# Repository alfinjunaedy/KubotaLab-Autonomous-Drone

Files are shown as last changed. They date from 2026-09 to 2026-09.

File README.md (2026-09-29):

# Autonomous Drone

<p align="center">
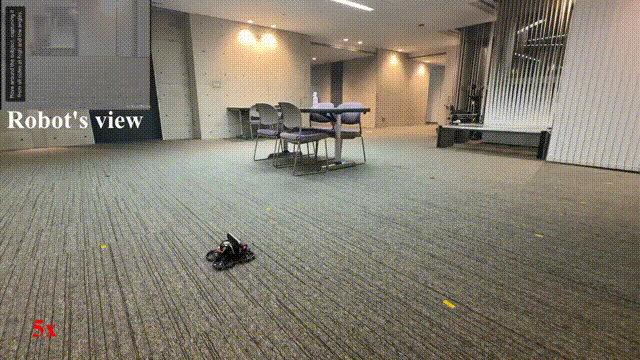
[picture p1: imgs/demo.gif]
Autonomous flight demo
  
</p>

Compact autonomous quadcopter built around a Raspberry Pi Zero 2 W. It estimates its position from an IMU, optical flow, and an altitude ToF sensor, then closes the loop on position and velocity onboard — no external positioning system required.

## Hardware

| | |
|---|---|
| Dimensions | 205 (L) × 205 (W) × 110 (H) mm |
| Weight | 877 g |
| Battery | Li-ion 6S pack (~5 min flight time) |
| Onboard controller | Raspberry Pi Zero 2 W |
| Sensors | IMU · optical flow · altitude ToF · A/D converter |
| Payload | iPhone 16 Pro |
| Flight controller | 4-in-1 ESC (Betaflight) |

<p align="center">
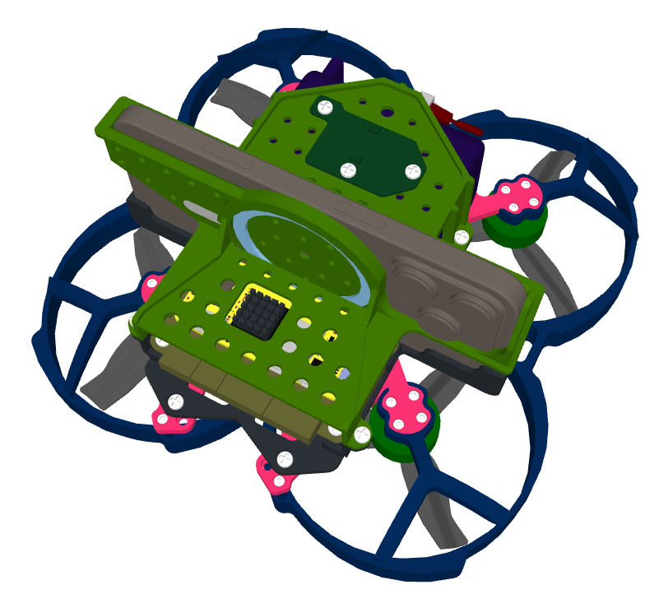
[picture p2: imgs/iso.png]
Isometric CAD view
  
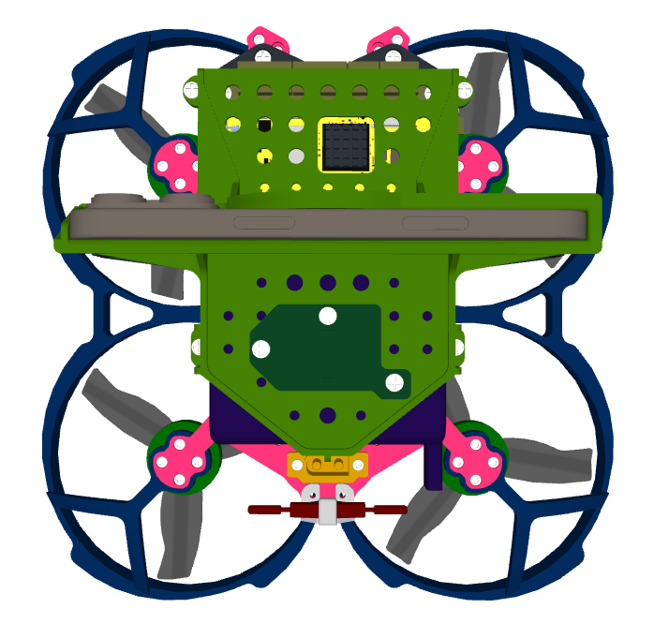
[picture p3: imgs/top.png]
Top CAD view
  
</p>

## Repository layout

```
├── cad/Assembly.step    # robot CAD design
├── imgs/                # demo.gif · iso.png · top.png
├── includes/            # include files
├── log/                 # binary flight logs (*.bin)
├── src/                 # source files
├── main.cpp             # main code
├── Makefile
└── plot_log_bin.py      # plot flight logs with Python
```

## Environment setup

The controller runs **Raspbian GNU/Linux 12 (Bookworm), armv7l 32-bit**. Prepare the system once before building the code.

**1. System packages** — SSH (remote access), Avahi (mDNS discovery), Samba (file shares for pulling `log/*.bin`), and monitoring tools:

```bash
sudo apt install openssh-server
sudo apt install samba
sudo apt install avahi-daemon
```

**2. [WiringPi](https://github.com/WiringPi/WiringPi)** — GPIO library, built and installed from source:

```bash
git clone https://github.com/WiringPi/WiringPi.git
cd WiringPi
./build debian
cd debian-template
sudo chmod +x wiringpi_3.2_armhf.deb
sudo apt install ./wiringpi_3.2_armhf.deb
sudo systemctl enable pigpiod
```

**3. Boot config** — edit `/boot/firmware/config.txt` and add the following below `[all]`:

```
dtoverlay=vc4-kms-v3d
enable_uart=1
dtoverlay=disable-bt
dtoverlay=dwc2,dr_mode=host
dtoverlay=i2c-gpio,bus=3,i2c_gpio_sda=4,i2c_gpio_scl=17,i2c_gpio_delay_us=2
over_voltage=2
arm_freq=1200
core_freq=500
```

This overclocks the Pi to 1.2 GHz, enables the UART (Bluetooth disabled to free it), puts USB into host mode, and bit-bangs I²C bus 3 on GPIO 4 (SDA) / GPIO 17 (SCL).

## Build

From the repository root:

```bash
make clean && make
```

## Software design

```
┌────────────────────────────────────────────────┐
│ Application — C++ (threads 0 / 1 / 2)          │
├────────────────────────────────────────────────┤
│ OS — Raspbian 12 Bookworm (32-bit)             │
├────────────────────────────────────────────────┤
│ Hardware — sensors · Pi Zero 2 W · 4-in-1 ESC  │
└────────────────────────────────────────────────┘
```

All threads run simultaneously:

- **Thread 0** — position control (100 Hz), CRFS communication (100 Hz)
- **Thread 1** — sensor readings (IMU 100 Hz, A/D conv 100 Hz, optical flow 10 Hz), position estimation (10 Hz), data logging (100 Hz)
- **Thread 2** — ToF reading (15 Hz), supervisor at 15 Hz (internal monitoring & management of flight and emergency states)

## Control design

```mermaid
flowchart LR
    subgraph sensors [Sensors]
        IMU[IMU]
        OF[Optical flow]
        TOF[ToF 8x8]
    end

    PE[Position estimation<br/>xyz · v_xyz · rpy · rates]

    subgraph control [Control]
        PC[Position control]
        VC[Velocity control]
        OC[Orientation control]
        GE[Ground effect compensation]
        SUM(("+"))
        FC[FC · motor mixing<br/>Betaflight 4-in-1 ESC]
    end

    USER([Target xyz · yaw])
    MOTORS([Motors])

    IMU --> PE
    OF --> PE
    TOF --> PE

    USER -->|target xyz| PC
    USER -->|target yaw| OC
    PC -->|target vel| VC

    VC -->|roll-pitch-thrust| SUM
    OC -->|yaw| SUM
    TOF -->|8x8 range| GE
    IMU --> GE
    GE -->|Δ roll-pitch-yaw-thrust| SUM
    SUM -->|roll-pitch-yaw-thrust| FC

    FC --> MOTORS

    PE -->|xyz| PC
    PE -->|v_xyz| VC
    PE -->|rpy · rates| OC
```

| Module | In | Out | Feedback |
|---|---|---|---|
| Position control | target xyz | target velocity | current xyz |
| Velocity control | target velocity | roll-pitch-thrust | current velocity |
| Orientation control | target yaw | target yaw | yaw, yaw rate |
| Position estimation | ToF 8×8, IMU, optical flow | xyz, v_xyz, rpy, rates | — |
| Ground effect | ToF 8×8, IMU | Δ roll-pitch-yaw-thrust (compensation) | — |
| FC | roll-pitch-yaw-thrust | motor mixing | — |

## Flight stages

| Stage | Code |
|---|---|
| Landed | 0 |
| Takeoff | 1 |
| Hover | 2 |
| Move | 3 |
| Landing | 4 |

## Emergency stages

**Emergency landing**

| Condition | Code |
|---|---|
| Battery ≤ 20 V | -1 |
| Altitude > 1.65 m | -2 |
| Sensor frequency < 50% of nominal | -3 |

**Emergency stop**

| Condition | Code |
|---|---|
| Linear velocity > ±0.65 m/s | -11 |
| Roll-pitch angle > ±25° | -12 |
| Sensor frequency = 0 Hz | -13 |
| Altitude > 1.95 m | -14 |
| Button | -15 |
| Angular velocity > ±180 °/s | -16 |

## Flight data

All flight data are stored in binary log files (`log/*.bin`). Plot them with:

```bash
python plot_log_bin.py [logfilename].bin
```

## License

Released under the [MIT License](LICENSE) — applies to the code, CAD, and documentation.

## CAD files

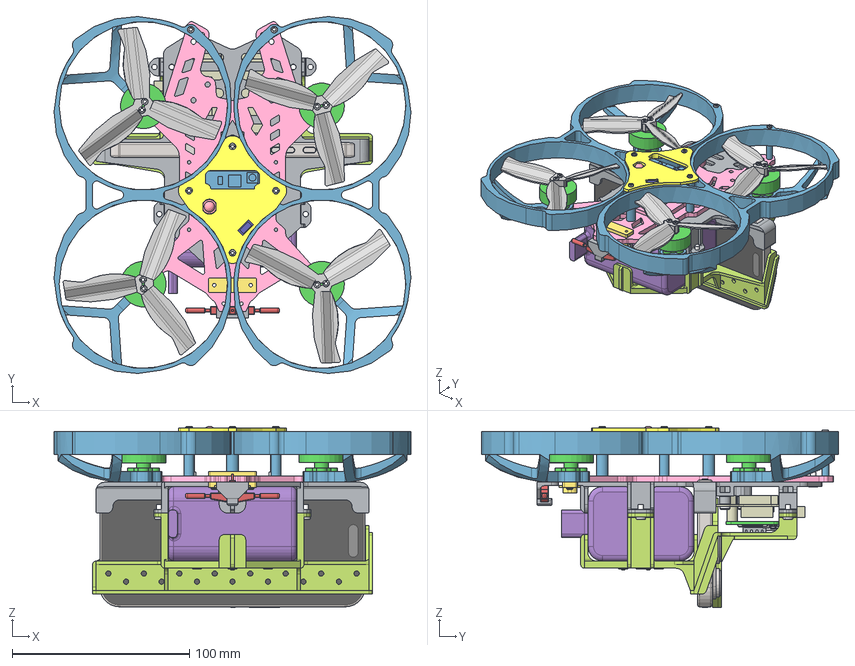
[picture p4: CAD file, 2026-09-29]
cad/Assembly.step
201.3 x 201.3 x 102.2 mm
PCB, Raspberry Pi Zero 2 W
RP3A0-AU 2105 201221C, Raspberry Pi Zero 2 W
MicroUSB Port, Raspberry Pi Zero 2 W
MicroUSB Port, Raspberry Pi Zero 2 W001
MicroUSB Port, Raspberry Pi Zero 2 W002
MicroUSB Port, Raspberry Pi Zero 2 W003
MicroUSB Port, Raspberry Pi Zero 2 W004
MicroUSB Port, Raspberry Pi Zero 2 W005
MicroUSB Port, Raspberry Pi Zero 2 W006
SD Card Slot, Raspberry Pi Zero 2 W
SD Card Slot, Raspberry Pi Zero 2 W001
SD Card Slot, Raspberry Pi Zero 2 W002
SD Card Slot, Raspberry Pi Zero 2 W003
SD Card Slot, Raspberry Pi Zero 2 W004
SD Card Slot, Raspberry Pi Zero 2 W005
SD Card Slot, Raspberry Pi Zero 2 W006
SD Card Slot, Raspberry Pi Zero 2 W007
SD Card Slot, Raspberry Pi Zero 2 W008
SD Card Slot, Raspberry Pi Zero 2 W009
Wireless Module Cover, Raspberry Pi Zero 2 W
Crystal Resonator, Raspberry Pi Zero 2 W
LED, Raspberry Pi Zero 2 W
Diode, Schottky, Raspberry Pi Zero 2 W
54548-2271, 22 Pin FPC Connector, Raspberry Pi Zero 2 W
Mini HDMI Receptacle Port, Raspberry Pi Zero 2 W
PAM2306AYPKE, Switching Voltage Regulators Dual PWM Step-Down 40uA 1A 1.5MHz, Raspberry Pi Zero 2 W
RT9081A-1BGQZA, Fixed LDO Voltage Regulator, 0.8V-5.5Vin, 140mV drop, 1.25Vout, 0.5Aout, Raspberry Pi Zero 2 W_default
RT8088AWSC, IC Reg Buck Prog 3A Sync 15WLCSP, Raspberry Pi Zero 2 W_default
SMD Inductor, Configurable, Raspberry Pi Zero 2 W_L1
SMD Inductor, Configurable, Raspberry Pi Zero 2 W_L2
SMD Capacitor, Configurable, Raspberry Pi Zero 2 W_C1
SMD Capacitor, Configurable, Raspberry Pi Zero 2 W_C001
SMD Capacitor, Configurable, Raspberry Pi Zero 2 W_C002
MicroUSB Port, Raspberry Pi Zero 2 W008
MicroUSB Port, Raspberry Pi Zero 2 W009
MicroUSB Port, Raspberry Pi Zero 2 W010
MicroUSB Port, Raspberry Pi Zero 2 W011
MicroUSB Port, Raspberry Pi Zero 2 W012
MicroUSB Port, Raspberry Pi Zero 2 W013
MicroUSB Port, Raspberry Pi Zero 2 W014
SMD Capacitor, Configurable, Raspberry Pi Zero 2 W_C3
SMD Capacitor, Configurable, Raspberry Pi Zero 2 W_C004
SMD Capacitor, Configurable, Raspberry Pi Zero 2 W_C005
SMD Capacitor, Configurable, Raspberry Pi Zero 2 W_C007
SMD Capacitor, Configurable, Raspberry Pi Zero 2 W_C008
SMD Capacitor, Configurable, Raspberry Pi Zero 2 W_C009
SMD Capacitor, Configurable, Raspberry Pi Zero 2 W_C011
SMD Capacitor, Configurable, Raspberry Pi Zero 2 W_C012
SMD Capacitor, Configurable, Raspberry Pi Zero 2 W_C013
SMD Capacitor, Configurable, Raspberry Pi Zero 2 W_C015
SMD Capacitor, Configurable, Raspberry Pi Zero 2 W_C016
SMD Capacitor, Configurable, Raspberry Pi Zero 2 W_C017
SMD Capacitor, Configurable, Raspberry Pi Zero 2 W_C019
SMD Capacitor, Configurable, Raspberry Pi Zero 2 W_C020
SMD Capacitor, Configurable, Raspberry Pi Zero 2 W_C021
SMD Capacitor, Configurable, Raspberry Pi Zero 2 W_C023
SMD Capacitor, Configurable, Raspberry Pi Zero 2 W_C024
SMD Capacitor, Configurable, Raspberry Pi Zero 2 W_C025
SMD Capacitor, Configurable, Raspberry Pi Zero 2 W_C027
SMD Capacitor, Configurable, Raspberry Pi Zero 2 W_C028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

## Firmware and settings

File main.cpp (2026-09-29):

/* ******************************************************************************************************** */
// by Alfin Junaedy, Kubota Lab - TMU, June 2026
// make clean && make
    // i2cdetect -y 1
    // i2cdetect -y 3
    // sudo systemctl restart pigpiod
/* ******************************************************************************************************** */

#include <asm/termbits.h>
#include <chrono>
#include <cmath>
#include <csignal>
#include <cstdint>
#include <cstdio>
#include <cstdlib>
#include <cstring>
#include <errno.h>
#include <fcntl.h>
#include <filesystem>
#include <fstream>
#include <iomanip>
#include <iostream>
#include <linux/i2c-dev.h>
#include <pigpiod_if2.h>
#include <stdint.h>
#include <string>
#include <sys/ioctl.h>
#include <sys/mman.h>
#include <sys/stat.h>
#include <thread>
#include <unistd.h>
#include <wiringPi.h>
#include <wiringPiI2C.h>
#include <wiringPiSPI.h>
#include <wiringSerial.h>

#include "ground_effect.hpp"
#include "ndo_leso.hpp"

extern "C" {
#include "vl53l5cx_api.h"
}

using namespace	std;
using namespace	std::chrono;
using clock0 = std::chrono::steady_clock;
using us0 = std::chrono::microseconds;

/* --------------------------------------------------------------- */
#define PIN_WPI_BUTF        26
#define PIN_WPI_BUTR        24
#define PIN_WPI_BUZZ        29
#define PIN_WPI_LEDR        4
#define PIN_WPI_LEDG        5
#define PIN_WPI_LEDB        6
#define PIN_WPI_LEDFLASH1   27
#define PIN_BCM_RX_OF       6
#define I2C_DEV_3           "/dev/i2c-3"
#define MUX_I2C_ADDR        0x70
#define ToF8x8_ADDR         0x29
#define ToF1_MUX_CH         2
#define ToF_FPS             30
#define I2C_DEV_1           "/dev/i2c-1"
#define BNO055_ADDR         0x28
#define ADS1115_ADDR        0x48
static constexpr uint8_t  CRSF_ADDR                 = 0xC8;
static constexpr uint8_t  CRSF_TYPE                 = 0x16;
static constexpr uint32_t CRSF_BAUD                 = 420000;
static constexpr const char* FC_SER_PORT            = "/dev/serial0";
static constexpr uint16_t MSP2_SENSOR_RANGEFINDER   = 0x1F01;
static constexpr uint16_t MSP2_SENSOR_OPTIC_FLOW    = 0x1F02;
static constexpr int BAUD_SOFT_OF                   = 115200;
static constexpr uint16_t MAX_OF_PAYLOAD            = 256;
static const string LOG_DIR                         = (filesystem::current_path() / "log").string() + "/";
static const string LOG_FILE                        = "dctllog";
static const float OFF_ROLL_CMD                     = -45;      // roll+=right (1000~2000)
static const float OFF_PITCH_CMD                    = -40;      // pitch+=forward (1000~2000)
static const float PX_SCALE_OF                      = 0.02f;    // (1/scale_ori)*(mea_real/mea_out) 
static const float HOVER_ALT_M                      = 0.3f;
static const float EMGC_LAND_BATT                   = 20.0f;    // volt
static const float EMGC_LAND_ALT                    = 1.65f;    // m
static const float EMGC_STOP_LINVEL                 = 1.2f;     // m/s
static const float EMGC_STOP_TILT                   = 25.0f;    // deg
static const float EMGC_STOP_ALT                    = 1.95f;    // m
static const float EMGC_STOP_ANGVEL                 = 180.0f;   // deg/s
static const int N_MAX_ODOM                         = 100;
static const float ODOM_LINVEL_TO                   = 0.1f;     // m/s
static const float ODOM_ANGVEL_TO                   = 15.0f;    // deg/s
static const int GE_state                           = 4;        // 1=PID 2=PID+scalar 3=PID+NDO 4=PID+GE
/* --------------------------------------------------------------- */

VL53L5CX_Configuration DevToF;
int fd_crsf_fc, fd_msp2_of, fd_i2c_1, fd_i2c_3;

float rpy_enc_deg[3], pos_ned[3], pos_neu[3], vel_ned[3], vel_rpy[3], flightTime=0;
int16_t adc_raw; float adc_volt;
float min_batt_volt=999, alt_of_m, flow_of_x, flow_of_y;
float tof1_m[64]={0}, tof1_avg_m=0, rc_cmd[16]={0}, tof1_single_m = 0;
const float emaFPS=0.25f, emaSYScpu=0.1f; float emaSYScpuVal[3]={0}; int cpuRAMtmp[3]={0};
float fps_main_th[3]={0}, fps_imu=0, fps_alt=0, fps_tof1=0, fps_adc=0, fps_of=0; 
int cnt_main_th[3]={0}, cnt_imu=0, cnt_alt=0, cnt_tof1=0, cnt_adc=0;
bool init_ready=false, init_stop=false, print_debug=false, startDctlLog=false, read_of=false;
int nDctlLog=0, dctlStages=0; float dctlLog150[150]={0};
bool startMission=false, z_ready=false, xy_ready=false;
int emgcCode=0, nOdom=0, mOdom=0, mOdomCur=0;
float odomGoal_NEU_CCW[N_MAX_ODOM][7]={0}, posTgtNeuDctl[4]={0}, posErrNeuDctl[4]={0}, ge_TRPY[8]={0};
bool SLOPE_START = false, gestart = false;
static float last_applied_pwm_ndo = 1500.0f;

PI_THREAD(th1_100);
PI_THREAD(th2_15);
void sigint_handler(int sig) {
    printf("\nForced close ... %d\n", sig);
    vl53l5cx_stop_ranging(&DevToF);
    if (fd_i2c_1 >= 0) { close(fd_i2c_1); fd_i2c_1 = -1; }
    if (fd_i2c_3 >= 0) { close(fd_i2c_3); fd_i2c_3 = -1; }
    if (fd_msp2_of >= 0) { bb_serial_read_close(fd_msp2_of, PIN_BCM_RX_OF); pigpio_stop(fd_msp2_of); fd_msp2_of = -1; } 
    if (fd_crsf_fc >= 0) { close(fd_crsf_fc); fd_crsf_fc = -1; }
    digitalWrite(PIN_WPI_BUZZ, 0);
    digitalWrite(PIN_WPI_LEDR, 0);
    digitalWrite(PIN_WPI_LEDG, 0);
    digitalWrite(PIN_WPI_LEDB, 0);
    digitalWrite(PIN_WPI_LEDFLASH1, 0);
    std::exit(0);
}

void set_buz_led(int buzz=0, int ledr=0, int ledg=0, int ledb=0, int ledf=0) {
    if (buzz >= 0) digitalWrite(PIN_WPI_BUZZ, buzz);
    if (ledr >= 0) digitalWrite(PIN_WPI_LEDR, ledr);
    if (ledg >= 0) digitalWrite(PIN_WPI_LEDG, ledg);
    if (ledb >= 0) digitalWrite(PIN_WPI_LEDB, ledb);
    if (ledf >= 0) digitalWrite(PIN_WPI_LEDFLASH1, ledf);
}
void getCPUramTmp(void) {
	try { // 0.2-1 ms
		// CPU usage %
		static unsigned int lastTotalUser, lastTotalUserLow, lastTotalSys, lastTotalIdle;
		unsigned long long totalUser, totalUserLow, totalSys, totalIdle, total;
		double percent;
		FILE* file;
		file = fopen("/proc/stat", "r");
		fscanf(file, "cpu %llu %llu %llu %llu", &totalUser, &totalUserLow, &totalSys, &totalIdle);
		fclose(file);
		if (totalUser < lastTotalUser || totalUserLow < lastTotalUserLow || totalSys < lastTotalSys || totalIdle < lastTotalIdle) { percent = -1.0; }
		else {
			total = (totalUser - lastTotalUser) + (totalUserLow - lastTotalUserLow) + (totalSys - lastTotalSys);
			percent = total * 100;
			total += (totalIdle - lastTotalIdle);
			percent /= total;
		}
		lastTotalUser = totalUser;
		lastTotalUserLow = totalUserLow;
		lastTotalSys = totalSys;
		lastTotalIdle = totalIdle;
		if (isnanf(percent) || isinf(percent) || percent <= 0) percent = cpuRAMtmp[0];
		else if (percent > 100) percent = 100;
		emaSYScpuVal[0] = (emaSYScpu * (float)percent) + ((1 - emaSYScpu) * emaSYScpuVal[0]);
		cpuRAMtmp[0] = round(emaSYScpuVal[0]);
		// MEM usage %
		ifstream meminfoFile("/proc/meminfo");
		string lineMem;
		unsigned long long totalMemory = 0;
		unsigned long long freeMemory = 0;
		while (getline(meminfoFile, lineMem)) {
			if (lineMem.find("MemTotal:") != string::npos) {
				istringstream iss(lineMem);
				iss.ignore(256, ':');
				iss >> totalMemory;
			}
			else if (lineMem.find("MemFree:") != string::npos) {
				istringstream iss(lineMem);
				iss.ignore(256, ':');
				iss >> freeMemory;
			}
		}
		unsigned long long ram = (long)round((float)(totalMemory - freeMemory) / 1024);
		if (isnan(ram) || isinf(ram) || ram <= 0) ram = cpuRAMtmp[1];
		else if (ram > 512) ram = 512;
		emaSYScpuVal[2] = (emaSYScpu * (float)ram) + ((1 - emaSYScpu) * emaSYScpuVal[2]); //MB
		cpuRAMtmp[1] = round(emaSYScpuVal[2] / 425.0 * 100.0); //MB to percent
		//CPU temp [degC]
		ifstream tempFile("/sys/class/thermal/thermal_zone0/temp");
		double temperature = 0.0;
		if (tempFile.is_open()) {
			string line;
			getline(tempFile, line);
			temperature = stod(line) / 1000.0;
			tempFile.close();
		}
		if (isnanf(temperature) || isinf(temperature) || temperature <= 0) temperature = cpuRAMtmp[2];
		else if (temperature > 100) temperature = 100;
		emaSYScpuVal[1] = (emaSYScpu * (float)temperature) + ((1 - emaSYScpu) * emaSYScpuVal[1]);
		cpuRAMtmp[2] = round(emaSYScpuVal[1]);
	}
	catch (const std::exception&) {
		cout << "Err reading CPU stats" << endl;
	}
}

static int open_ser_crsf_fc(const char *dev) {
    int fd = open(dev, O_RDWR | O_NOCTTY | O_SYNC);
    if (fd < 0) return -1;
    termios2 tty{};
    if (ioctl(fd, TCGETS2, &tty) < 0) return -1;
    tty.c_cflag &= ~CBAUD;
    tty.c_cflag |= BOTHER;
    tty.c_ispeed = CRSF_BAUD;
    tty.c_ospeed = CRSF_BAUD;
    tty.c_cflag = (tty.c_cflag & ~CSIZE) | CS8;
    tty.c_cflag &= ~PARENB;
    tty.c_cflag &= ~CSTOPB;
    tty.c_cflag &= ~CRTSCTS;
    tty.c_cflag |= CLOCAL | CREAD;
    tty.c_iflag = tty.c_oflag = tty.c_lflag = 0;
    if (ioctl(fd, TCSETS2, &tty) < 0) return -1;
    if (ioctl(fd, TCFLSH, TCIOFLUSH) < 0) return -1;
    return fd;
}
static int open_ser_msp2_of(void) {
    int fd = pigpio_start(nullptr, nullptr);
    if (fd < 0) return -1;
    if (bb_serial_read_open(fd, PIN_BCM_RX_OF, BAUD_SOFT_OF, 8) != 0) { pigpio_stop(fd); return -1; }
    return fd;
}
static int imu_init(int fd) {
    uint8_t config[2] = {0x3D, 0x0C};
    if (ioctl(fd, I2C_SLAVE, BNO055_ADDR) < 0) return -1;
    if (write(fd, config, 2) < 0) return -1;
    return 0;
}
static int adc_init(int fd) {
    uint8_t config[3] = {0x01,0xC2,0x83};
    if (ioctl(fd, I2C_SLAVE, ADS1115_ADDR) < 0) return -1;
    if (write(fd, config, 3) < 0) return -1;
    return 0;
}
static int tof_init(int fd) {
    DevToF.platform.fd = fd;
    DevToF.platform.address = ToF8x8_ADDR;
    // select mux ch
    uint8_t data = (1 << ToF1_MUX_CH); 
    if (ioctl(DevToF.platform.fd, I2C_SLAVE, MUX_I2C_ADDR) < 0) return -1;
    if (write(DevToF.platform.fd, &data, 1) != 1) return -1;
    usleep(5000);
    // init
    if (ioctl(DevToF.platform.fd, I2C_SLAVE, DevToF.platform.address) < 0) return -1;
    uint8_t isAlive = 0, status;
    status = vl53l5cx_is_alive(&DevToF, &isAlive);
    if (!isAlive || status) return -1;
    status = vl53l5cx_init(&DevToF);
    if (status) return -1;
    vl53l5cx_set_resolution(&DevToF, VL53L5CX_RESOLUTION_8X8);
    vl53l5cx_set_ranging_frequency_hz(&DevToF, ToF_FPS);
    vl53l5cx_start_ranging(&DevToF);
    return 0;
}

static int build_crsf_frame(uint8_t *out, uint16_t ch_us[16]) {
    uint8_t payload[22] = {};
    for (int i = 0; i < 16; i++) {
        if (ch_us[i] < 1000) ch_us[i] = 1000;
        if (ch_us[i] > 2000) ch_us[i] = 2000;
        ch_us[i] = 172 + (ch_us[i] - 1000) * (1811 - 172) / 1000;
        //---
        uint16_t v = ch_us[i] & 0x07FF;
        int bit = i * 11;
        int b = bit / 8;
        int s = bit % 8;
        payload[b]     |= (v << s);
        payload[b + 1] |= (v >> (8 - s));
        if (s > 5) payload[b + 2] |= (v >> (16 - s));
    }
    out[0] = CRSF_ADDR;
    out[1] = 24;
    out[2] = CRSF_TYPE;
    memcpy(out + 3, payload, 22);
    const uint8_t *buf = out+2; size_t len = 23; uint8_t crc = 0;
    while (len--) {
        crc ^= *buf++;
        for (int i = 0; i < 8; i++)
            crc = (crc & 0x80) ? (crc << 1) ^ 0xD5 : (crc << 1);
    }
    out[25] = crc;
    return 26;
}
static uint8_t crc8_dvb_s2(uint8_t crc, uint8_t b) {
    crc ^= b;
    for (int i = 0; i < 8; i++) { crc = (crc & 0x80) ? (crc << 1) ^ 0xD5 : (crc << 1); }
    return crc;
}
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
int main(void) {
    signal(SIGINT, sigint_handler);
    wiringPiSetup();
    pinMode(PIN_WPI_BUTF, INPUT);
    pinMode(PIN_WPI_BUTR, INPUT);
    pinMode(PIN_WPI_BUZZ, OUTPUT);
    pinMode(PIN_WPI_LEDR, OUTPUT);
    pinMode(PIN_WPI_LEDG, OUTPUT);
    pinMode(PIN_WPI_LEDB, OUTPUT);
    pinMode(PIN_WPI_LEDFLASH1, OUTPUT);

    cout << ">>> Initializing ..." << endl;
    set_buz_led(1,0,0,0,0); delay(50); 
    set_buz_led(0,0,0,0,0); delay(50);
    piThreadCreate(th1_100);
    piThreadCreate(th2_15);

    fd_crsf_fc = open_ser_crsf_fc(FC_SER_PORT); 
    if (fd_crsf_fc < 0) {cout << "[Bad] Serial FC" << endl; return -1;}
    cout << ">>> [OK] Serial FC" << endl; delay(50);
    fd_msp2_of = open_ser_msp2_of(); 
    if (fd_msp2_of < 0) {cout << "[Bad] Serial OF" << endl; return -1;}
    cout << ">>> [OK] Serial OF" << endl; delay(50);
    fd_i2c_1 = open(I2C_DEV_1, O_RDWR);
    fd_i2c_3 = open(I2C_DEV_3, O_RDWR);
    if (fd_i2c_1 < 0) {cout << "[Bad] I2C-1" << endl; return -1;}
    if (fd_i2c_3 < 0) {cout << "[Bad] I2C-3" << endl; return -1;}
    cout << ">>> [OK] I2C-1 I2C-3" << endl; delay(50);
    if (imu_init(fd_i2c_1) < 0) {cout << "[Bad] IMU" << endl; return -1;}
    cout << ">>> [OK] IMU" << endl; delay(50);
    if (adc_init(fd_i2c_1) < 0) {cout << "[Bad] ADC" << endl; return -1;}
    cout << ">>> [OK] ADC" << endl; delay(50);
    if (tof_init(fd_i2c_3) < 0) {cout << "[Bad] ToF1" << endl; return -1;}
    cout << ">>> [OK] ToF1" << endl; delay(50);
    if (!init_stop) { init_ready = true; cout << ">>> Starting ..." << endl; }
    while (fps_main_th[1] < 50 || fps_main_th[2] < 7 || fps_imu < 50 || fps_of < 5 || fps_alt < 15 || fps_tof1 < 7 || fps_adc < 50 || init_stop) { 
        if (!digitalRead(PIN_WPI_BUTF) || !digitalRead(PIN_WPI_BUTR)) { init_stop = true; } 
        delay(100);
    }

    uint16_t ch_us_mot[16]; uint8_t frame_mot[26]; int mot_seq=0;
    float posPID[3][3]={0}, tmpIpos[3]={0}, posErrNeuDctlPrev[4]={0}, vel_tgt_NED[3]={0};
    float velPID[3][3]={0}, tmpIvel[3]={0}, velErrNedDctlPrev[3]={0}, velErrNedDctl[3]={0};
    float Fxyz_NEU[3]={0}, Fyaw_CW=0, vxy_world[2]={0};
    float yawPID[3]={0}, tmpYPID=0, flagYawPrev=0;
    bool frs_print=true, flagYawDone=false;
    float Throttle_Ft=0, RPY_ref[3]={0}, Throttle_prev=0;
    float mg_tmp=1000, vel_tgtZ_prev=0, Fu=0; 
    bool isHover = false, isXYreset = false;
    int dctlStages_prev = 0;
    float cmd_TRP_slope[3] = {0};

    const float mg_throttle     = 1400;
    const float maxThrottle     = 1600;
    const float maxFz           = 75;
    const float maxFxy          = 150;
    const float maxFyaw         = 100;
    const float RCcenter        = 1500;
    const float dt100Hz         = 1.0f / 100.0f;
    const float dt10Hz          = 1.0f / 10.0f;
    const float dt15Hz          = 1.0f / 15.0f;
    const float kPIDvelZ[3]     = {80,200,15};
    const float kPIDposZ[3]     = {0.8,0.15,0.10};
    const float kPIDvelXY[3]    = {115,30,50};
    const float kPIDposXY[3]    = {0.65,0.04,0.05};
    const float kPIDyaw[3]      = {6,0.1,0.05};

    auto t0a = high_resolution_clock::now();
    auto ticFTsec = [&]() { t0a = high_resolution_clock::now(); };
    auto tocFTsec = [&]() { return (float)(high_resolution_clock::now() - t0a).count() / 1000000000; };
    auto sindeg = [&](float deg) { return sin((deg * M_PI) / 180.0); };
	auto cosdeg = [&](float deg) { return cos((deg * M_PI) / 180.0); };
	auto tandeg = [&](float deg) { return tan((deg * M_PI) / 180.0); };
    auto motDisArm = [&]() {
        rc_cmd[0] = RCcenter; // roll
        rc_cmd[1] = RCcenter; // pitch
        rc_cmd[3] = RCcenter; // yaw
        rc_cmd[2] = 1000; // throttle (1000-2000)
        rc_cmd[4] = 2000; // AUX1: arm (on: 900-1200)
    };
    auto motArm = [&]() {
        rc_cmd[0] = RCcenter; // roll
        rc_cmd[1] = RCcenter; // pitch
        rc_cmd[3] = RCcenter; // yaw
        rc_cmd[2] = 1000; // throttle (1000-2000)
        rc_cmd[4] = 1000; // AUX1: arm (on: 900-1200)
    };
    auto motFlightPID = [&]() {
        if (z_ready) {
            z_ready = false;
            if (dctlStages == 1) {
                posTgtNeuDctl[2] += 0.025f; //0.050 0.01
                posTgtNeuDctl[2] = min(posTgtNeuDctl[2], HOVER_ALT_M);
            }
            else if (dctlStages == 4) {
                posTgtNeuDctl[2] -= 0.01f; //0.015 0.025
                posTgtNeuDctl[2] = max(posTgtNeuDctl[2], 0.0f);
            }
            // Error pos (NEU) -------------------------------------------------------------
            posErrNeuDctl[2] = posTgtNeuDctl[2] - pos_neu[2];
            float errSat = 0.200f; // m
            if (posErrNeuDctl[2] > errSat) posErrNeuDctl[2] = errSat; else if (posErrNeuDctl[2] < -errSat) posErrNeuDctl[2] = -errSat;            
            // PID z -----------------------------------------------------------------------
            errSat = 0.200f; // m/s
            tmpIpos[2] += posErrNeuDctl[2] * dt15Hz;            
            posPID[2][0] = kPIDposZ[0] * posErrNeuDctl[2];
            posPID[2][1] = kPIDposZ[1] * tmpIpos[2];
            posPID[2][2] = kPIDposZ[2] * (posErrNeuDctl[2] - posErrNeuDctlPrev[2]) / dt15Hz;
            posErrNeuDctlPrev[2] = posErrNeuDctl[2];
            if (isnan(posPID[2][0]) || isinf(posPID[2][0])) posPID[2][0] = 0.0f;
            if (isnan(posPID[2][1]) || isinf(posPID[2][1])) posPID[2][1] = 0.0f;
            if (isnan(posPID[2][2]) || isinf(posPID[2][2])) posPID[2][2] = 0.0f;
            vel_tgt_NED[2] = -(posPID[2][0] + posPID[2][1] + posPID[2][2]); // world(NEU) to body(NED)
            if (vel_tgt_NED[2] > errSat) vel_tgt_NED[2] = errSat; else if (vel_tgt_NED[2] < -errSat) vel_tgt_NED[2] = -errSat;
            if (dctlStages == 1) {
                if (vel_tgt_NED[2] > vel_tgtZ_prev) vel_tgt_NED[2] = vel_tgtZ_prev;
            }
            vel_tgtZ_prev = vel_tgt_NED[2];
            // Error vel (NED) -------------------------------------------------------------
            velErrNedDctl[2] = vel_tgt_NED[2] - vel_ned[2];
            if (velErrNedDctl[2] > errSat) velErrNedDctl[2] = errSat; else if (velErrNedDctl[2] < -errSat) velErrNedDctl[2] = -errSat;
            // PID vz ----------------------------------------------------------------------
            tmpIvel[2] += velErrNedDctl[2] * dt15Hz;
            velPID[2][0] = kPIDvelZ[0] * velErrNedDctl[2];
            velPID[2][1] = kPIDvelZ[1] * tmpIvel[2];
            velPID[2][2] = kPIDvelZ[2] * (velErrNedDctl[2] - velErrNedDctlPrev[2]) / dt15Hz;
            velErrNedDctlPrev[2] = velErrNedDctl[2];
            if (isnan(velPID[2][0]) || isinf(velPID[2][0])) velPID[2][0] = 0.0f;
            if (isnan(velPID[2][1]) || isinf(velPID[2][1])) velPID[2][1] = 0.0f;
            if (isnan(velPID[2][2]) || isinf(velPID[2][2])) velPID[2][2] = 0.0f;
            Fxyz_NEU[2] = -(velPID[2][0] + velPID[2][1] + velPID[2][2]); // Invert
            if (Fxyz_NEU[2] > maxFz) Fxyz_NEU[2] = maxFz; else if (Fxyz_NEU[2] < -maxFz) Fxyz_NEU[2] = -maxFz;
            // Conversion
            if (!isHover) {
                mg_tmp += 15; //35 50
                mg_tmp = min(mg_tmp, mg_throttle);
                if (dctlStages == 2) {
                    isHover = true;
                    mg_tmp = Fu;
                    tmpIpos[2] = 0; tmpIvel[2] = 0;
                }
            }
            Fu = Fxyz_NEU[2] + mg_tmp;
            Throttle_Ft = Fu / (cosdeg(rpy_enc_deg[0]) * cosdeg(rpy_enc_deg[1]));
            // Output saturation ----------------------------------------------------------           
            if (Throttle_Ft > maxThrottle) Throttle_Ft = maxThrottle;
            Throttle_prev = Throttle_Ft;
            // log 105~109 110~114
            dctlLog150[105] = -velPID[2][0]; dctlLog150[106] = -velPID[2][1]; dctlLog150[107] = -velPID[2][2]; dctlLog150[108] = Fxyz_NEU[2]; dctlLog150[109] = -vel_tgt_NED[2];    // NEU
            dctlLog150[110] = posPID[2][0]; dctlLog150[111] = posPID[2][1]; dctlLog150[112] = posPID[2][2]; dctlLog150[113] = -vel_tgt_NED[2]; dctlLog150[114] = posTgtNeuDctl[2];  // NEU
        }
        if (xy_ready) {
            xy_ready = false;
            if (!isXYreset && dctlStages == 3) {
                if (odomGoal_NEU_CCW[mOdomCur][4] >= 1 && odomGoal_NEU_CCW[mOdomCur][4] <= 4) {
                    isXYreset = true;
                    tmpIpos[0] = 0; tmpIpos[1] = 0;
                    tmpIvel[0] = 0; tmpIvel[1] = 0;
                }
            }
            if (dctlStages == 2) isXYreset = false;
            float rotPD[2] = {1,1};
            if (dctlStages == 3) {
                if (odomGoal_NEU_CCW[mOdomCur][4] >= 7 && odomGoal_NEU_CCW[mOdomCur][4] <= 8) {
                    tmpIpos[0] = 0; tmpIpos[1] = 0;
                    tmpIvel[0] = 0; tmpIvel[1] = 0;
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

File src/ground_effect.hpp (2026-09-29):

#include <cmath>
#include <cstdint>
#include <algorithm>
#include <array>

// ============================================================================
//   body frame: x = forward(+), y = right(+), z = down(+)
//   roll  input: degrees, POSITIVE = right side down
//   pitch input: degrees, POSITIVE = nose down
// ============================================================================

namespace ge {

constexpr int    kN            = 8;       // Array size, 8x8 zones
constexpr double kHFOV_deg     = 45.0;    // [deg] FoV
constexpr double kVFOV_deg     = 45.0;    // [deg] FoV
constexpr double kPsiS_deg     = 135.0;   // [deg] sensor mounting yaw

constexpr double kXs           = 0.018;   // [m] sensor offset from CoM, +forward
constexpr double kYs           = 0.008;   // [m] sensor offset from CoM, +right
constexpr double kZs           = 0.0;     // [m] sensor offset from CoM, +down

constexpr double kRProp        = 0.045;   // [m] propeller radius
constexpr double kRhoGE        = 3.5;     // [-] empirical GE coefficient
constexpr double kMass         = 0.877;   // [kg]
constexpr double kG            = 9.81;    // [m/s^2] gravity
constexpr double kThrottleHover= 0.55;    // [0~1] hover throttle

constexpr double kHMin         = 0.05;    // [m] clearance floor (avoid singularity)
constexpr double kHThreshold   = 4.0 * kRProp;  // [m] beyond this, GE ~negligible
constexpr double kEth          = 0.03;    // [m] RMS plane-fit validity threshold -- tune
constexpr int    kNMin         = 16;      // min valid zones for a trustworthy fit
constexpr double kDropFrac     = 0.2;     // RANSAC-lite: fraction of worst zones dropped
constexpr double kRMinValid    = 0.02;    // [m] sensor min usable range
constexpr double kRMaxValid    = 4.0;     // [m] sensor max usable range

// Rotor arm offsets, X-config, x=forward(+) y=right(+).
constexpr double kArmLen       = 0.050;    // [m]
constexpr double kArmProj      = kArmLen * 0.70710678118654752;  // L/sqrt(2)

struct RotorPos { double x, y; const char* label; };
constexpr RotorPos kRotors[4] = {
    { +kArmProj, +kArmProj, "FR (front-right)" },
    { +kArmProj, -kArmProj, "FL (front-left)"  },
    { -kArmProj, +kArmProj, "RR (rear-right)"  },
    { -kArmProj, -kArmProj, "RL (rear-left)"   },
};

inline double deg2rad(double d) { return d * M_PI / 180.0; }

struct Vec3 { double x, y, z; };

inline Vec3 rotZ(const Vec3& v, double psi) {
    double c = std::cos(psi), s = std::sin(psi);
    return { c*v.x - s*v.y, s*v.x + c*v.y, v.z };
}

struct ZoneDirTable {
    Vec3 d[64];
    ZoneDirTable() {
        const double hfov = deg2rad(kHFOV_deg);
        const double vfov = deg2rad(kVFOV_deg);
        const double psi_s = deg2rad(kPsiS_deg);
        for (int iy = 0; iy < kN; ++iy) {
            double ty = -vfov/2.0 + (iy + 0.5) * vfov / kN;
            for (int ix = 0; ix < kN; ++ix) {
                double tx = -hfov/2.0 + (ix + 0.5) * hfov / kN;
                double denom = std::sqrt(1.0 + std::tan(tx)*std::tan(tx)
                                              + std::tan(ty)*std::tan(ty));
                Vec3 dsensor { std::tan(tx)/denom, std::tan(ty)/denom, 1.0/denom };
                d[iy*kN + ix] = rotZ(dsensor, psi_s);   // fold in mounting yaw once
            }
        }
    }
};
static const ZoneDirTable kZoneDirs;

inline void Rx(double phi, double R[3][3]) {
    double c = std::cos(phi), s = std::sin(phi);
    R[0][0]=1; R[0][1]=0;  R[0][2]=0;
    R[1][0]=0; R[1][1]=c;  R[1][2]=-s;
    R[2][0]=0; R[2][1]=s;  R[2][2]=c;
}
inline void RyCorrected(double theta, double R[3][3]) {
    double c = std::cos(theta), s = std::sin(theta);
    R[0][0]=c;  R[0][1]=0; R[0][2]=-s;
    R[1][0]=0;  R[1][1]=1; R[1][2]=0;
    R[2][0]=s;  R[2][1]=0; R[2][2]=c;
}
inline void matmul3(const double A[3][3], const double B[3][3], double Cm[3][3]) {
    for (int i=0;i<3;++i)
        for (int j=0;j<3;++j) {
            double s=0;
            for (int k=0;k<3;++k) s += A[i][k]*B[k][j];
            Cm[i][j]=s;
        }
}
inline Vec3 matvec3(const double R[3][3], const Vec3& v) {
    return { R[0][0]*v.x+R[0][1]*v.y+R[0][2]*v.z,
             R[1][0]*v.x+R[1][1]*v.y+R[1][2]*v.z,
             R[2][0]*v.x+R[2][1]*v.y+R[2][2]*v.z };
}

struct Plane { double a=0, b=0, c=0; bool ok=false; };

inline Plane fitPlane(const Vec3* pts, const int* idx, int n) {
    Plane out;
    if (n < 3) return out;

    double Sxx=0, Sxy=0, Sx=0, Syy=0, Sy=0, S1=0;
    double Sxz=0, Syz=0, Sz=0;
    for (int k=0; k<n; ++k) {
        const Vec3& p = pts[idx[k]];
        Sxx += p.x*p.x; Sxy += p.x*p.y; Sx += p.x;
        Syy += p.y*p.y; Sy += p.y;      S1 += 1.0;
        Sxz += p.x*p.z; Syz += p.y*p.z; Sz += p.z;
    }
    // Solve [Sxx Sxy Sx; Sxy Syy Sy; Sx Sy S1] * [a b c]^T = [Sxz Syz Sz]^T
    double M[3][3] = {{Sxx,Sxy,Sx},{Sxy,Syy,Sy},{Sx,Sy,S1}};
    double rhs[3]  = {Sxz, Syz, Sz};

    // 3x3 closed-form inverse via cofactors
    double det = M[0][0]*(M[1][1]*M[2][2]-M[1][2]*M[2][1])
               - M[0][1]*(M[1][0]*M[2][2]-M[1][2]*M[2][0])
               + M[0][2]*(M[1][0]*M[2][1]-M[1][1]*M[2][0]);
    if (std::fabs(det) < 1e-12) return out;

    double inv[3][3];
    inv[0][0] =  (M[1][1]*M[2][2]-M[1][2]*M[2][1]) / det;
    inv[0][1] = -(M[0][1]*M[2][2]-M[0][2]*M[2][1]) / det;
    inv[0][2] =  (M[0][1]*M[1][2]-M[0][2]*M[1][1]) / det;
    inv[1][0] = -(M[1][0]*M[2][2]-M[1][2]*M[2][0]) / det;
    inv[1][1] =  (M[0][0]*M[2][2]-M[0][2]*M[2][0]) / det;
    inv[1][2] = -(M[0][0]*M[1][2]-M[0][2]*M[1][0]) / det;
    inv[2][0] =  (M[1][0]*M[2][1]-M[1][1]*M[2][0]) / det;
    inv[2][1] = -(M[0][0]*M[2][1]-M[0][1]*M[2][0]) / det;
    inv[2][2] =  (M[0][0]*M[1][1]-M[0][1]*M[1][0]) / det;

    out.a = inv[0][0]*rhs[0] + inv[0][1]*rhs[1] + inv[0][2]*rhs[2];
    out.b = inv[1][0]*rhs[0] + inv[1][1]*rhs[1] + inv[1][2]*rhs[2];
    out.c = inv[2][0]*rhs[0] + inv[2][1]*rhs[1] + inv[2][2]*rhs[2];
    out.ok = true;
    return out;
}

struct GEResult {
    bool   valid = false;
    double alpha_rad = 0.0;
    double h_eff = 0.0;
    double e_rms = 0.0;
    int    n_valid = 0;
    double dT_ff = 0.0;
    double h_motor[4]   = {0,0,0,0}; // per-rotor clearance, order = kRotors
    double dT_motor[4]  = {0,0,0,0}; // per-rotor feedforward correction
};
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
